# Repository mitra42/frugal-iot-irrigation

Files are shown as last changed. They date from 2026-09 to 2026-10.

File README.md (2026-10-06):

# Frugal-IoT Irrigation

This project is intended to provide solar-powered irrigation for small farms. A set of sectors is watered one at a time, once a day,
each until its soil reaches a target moisture or a time limit runs out, 
with tank-level and battery interlocks that stop the whole run.

It is built on top of Frugal-IoT and both the irrigation and MPPT components draw part of their
inpiration from [OSPIT](https://www.apc.org/en/news/meet-ospit-sustainable-energy-and-irrigation-solution-community-networks)
(Lua on the FF-ESP32-OpenMPPT solar charge controller)
- [OSPIT_COMPARISON.md](OSPIT_COMPARISON.md) describes what is different and why.

This release should work in two hardware environments.

a: The "FF-ESP32-OpenMPPT solar charge controller" in which case it will run MPPT 
This release should work - and do MPPT - on both the "FF-ESP32-OpenMPPT solar charge controller", 
or work without MPPT on  that OSPIT runs on, and 
any similar system of sensors, and pumps. 

[Frugal-IoT](https://github.com/mitra42/frugal-iot) brings: WiFi setup from a phone; MQTT; web and phone dashboards; graphing and over-the-air updates.  

Any of the other features of Frugal-IoT can be easily added to your sketch including, off-internet operation, remote sensors, LoRa, or a wide range of other sensors for example for weather. 

## What it does today

- **Up to N irrigation sectors**, run strictly in order, one valve open at a time.
- **Soil moisture per sector** from RS485/Modbus probes sharing one bus, or from simple analog
  capacitive soil sensors.
- Anomaly handling - for instance, a sector whose probe is **not reporting is skipped**
- **Tank level** from a float sender, with two thresholds: one to begin a run, a lower one to
  abort it. "No tank sensor fitted" is kept distinct from "tank empty".
- **Battery interlock** - irrigation stops below a configurable voltage and resumes above a higher
  one.
- Optional **pump** (driven with the valves) and **load output** (e.g. for a router) (switched by the
  battery interlock) on separate pins.
- Optional **OLED**: Displays battery; sector moistures; tank and communicationss status.
- **Solar charge control** - two-stage MPPT tracking with temperature compensation, a hard
  thermal cut-out, and battery-type profiles.
- **Battery reporting** - state of charge and a health estimate inferred from voltage drop.

## Status

**None of the charge control has run on real hardware yet**, so it ships switched off. 

Run the checks in [TESTING.md](TESTING.md) and then turn on `mppt/automatic`

`HARDWARE-QUESTIONS.md` is a list of things we need someone with the OSPIT hardware to
look at and confirm.

## Hardware

Two boards are supported out of the box. See `platformio.ini` for the full pin list.

| Board | Notes |
|---|---|
| **FF-ESP32-OpenMPPT** | the solar charge controller OSPIT runs on. Pin assignments are OSPIT's own |
| **Lolin S2 Mini** | the same application on a plain dev board, no charging hardware. [docs/hardware/s2_mini](docs/hardware/s2_mini/) is a full reference design - schematic, wiring diagram and BOM |
| other | Setting up support for most other boards is trivial, look in the [Frugal-IoT/examples/all](https://github.com/mitra42/frugal-iot/blob/main/examples/all/platformio.ini) for example configuration for many popular boards or [add a new issue](https://github.com/mitra42/frugal-iot-irrigation/issues/new) in this repo.

You will also need: 12 V valves and a driver for them, one Modbus soil probe per sector, an RS485
transceiver, and optionally a tank float sender and a pump.

For the Lolin S2 Mini there is now a worked hardware design in [docs/hardware/s2_mini](docs/hardware/s2_mini/) at BOM cost about $9/controller + ~$22/sector, detailed explanation of choices in 
[README](docs/hardware/s2_mini/README.md). 

## Building

### PlatformIO (recommended)

```bash
pio run --environment ff_openmppt          # compile
pio run --target upload -e ff_openmppt     # flash
pio run --target uploadfs -e ff_openmppt   # upload data/ (WiFi passwords etc)
```

The Frugal-IoT library is fetched automatically, so a fresh clone needs nothing set up. 
If you are changing the library at the same time, 
see "Building against a local library" in [CLAUDE.md](CLAUDE.md).

### Arduino IDE

1. Install **Frugal-IoT** from Library Manager (or clone it into your `libraries/` folder).
2. Install the ESP32 board support package.
3. Open `frugal-iot-irrigation.ino` - the whole repository folder is the sketch folder.
4. Under **Tools > Board**, pick the board you have. `platform.h` supplies the right pins for it;
   if your board has no section there, compiling stops with a message telling you so.

`platform.h` is generated from `platformio.ini`. If you change pins there, re-run
`scripts/generate_platform_h.bash`, or the two toolchains will disagree.

## First run

1. Flash, then power up. The device makes its own WiFi network - connect a phone to it.
2. A setup page opens (or browse to `192.168.4.1`). Give it your WiFi name and password.
3. **Irrigation starts switched off.** Turn it on in the **Irrigation** section, and set
   the start time while you are there.

`TESTING.md` walks through commissioning a real board step by step, including calibrating the tank
and the battery. `HARDWARE-QUESTIONS.md` is a list of things we need someone with the hardware to
look at.

[docs/bom.md](docs/bom.md) lists the hardware the original OSPIT system is built from - the board,
the sensors, the valves, the pump - with a source for every line.

Because not everyone has sun, a multimeter and a fortnight, `docs/` holds three ready-made plans —
[bench](docs/plan-bench.md), [sunny half-day](docs/plan-sunny-session.md),
[days of running](docs/plan-long-run.md) — each a short ordered list of which Parts of `TESTING.md`
to do. Question 9 of `HARDWARE-QUESTIONS.md` picks one. [docs/sleep-test.md](docs/sleep-test.md) is
the one test that needs its own build, on the `sleep-test` branch.

## Licence

Same as Frugal-IoT. The OSPIT algorithms parts of this are derived from are GPL-2.0-or-later,
Copyright (C) 2026 Corinna 'Elektra' Aichele.

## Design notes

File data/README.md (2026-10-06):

# `data/` - files uploaded to the device's own filesystem

Everything here is copied onto the device with:

    pio run --target uploadfs --environment ff_openmppt

It is **not** part of the firmware, so changing a WiFi password does not mean recompiling.

## The layout: one flat file per setting

Every file sits directly in `data/`, named `<module>.<setting>`, and its contents are the value.
There are no subdirectories - on LittleFS each directory costs a whole 8KB block, which filled the
filesystem on small boards. (A board still holding the old `wifi/`, `frugal_iot/` directories
converts them to this layout by itself, once, at boot.)

Two characters in a name have to be written as codes, because `.` separates the parts:

| In the real name | Write it as |
|---|---|
| `.` | `%2E` |
| `%` | `%25` |

### `wifi.<network name>`

One file per network. The rest of the **file name** is the network name (SSID) and the
**contents** are the password, nothing else - no newline at the end. A device tries every network
it finds a file for, so you can leave several here.

    data/wifi.MyHomeWiFi            <- contains the password
    data/wifi.Cafe 2%2E4G           <- the network called "Cafe 2.4G"

### `frugal_iot.<setting>`

Device settings. The commonest are `project` and `description`, which decide where the device's
readings appear and what it is called on the dashboard.

    data/frugal_iot.project         <- e.g. lotus
    data/frugal_iot.description     <- e.g. Irrigation north field

Any other setting saved from the dashboard is stored the same way - `mppt.automatic`, for example.
You can put one here to have a board start with it.

Every `wifi.*` and `frugal_iot.*` file is in `.gitignore`, because they hold passwords and
site details. This README is not.

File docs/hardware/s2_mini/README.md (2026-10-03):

# Lolin S2 Mini irrigation node — reference hardware

A worked design for the hardware the **`s2_mini`** build needs around it. 

Feel free to modify to your own needs, but check the reasoning below for our design choices so
you can intentionally disagree with them. 

Note - as of September 2026 - none of this has been built on hardware and tested. 

| File | What |
|---|---|
| [`wiring.md`](wiring.md) | **the connection table — the authoritative reference** |
| [`wiring.svg`](wiring.svg) | the same thing as a picture, for assembly |
| [`schematic.pdf`](schematic.pdf) | the circuit, with the values and the reasoning on the sheet |
| [`bom.md`](bom.md) | what to buy, with AliExpress search terms |
| [`bom.csv`](bom.csv) | generated from the schematic |
| [`check_wiring.py`](check_wiring.py) | checks `platformio.ini`, `wiring.md` and the schematic still agree |
| `s2_mini_irrigation.kicad_sch` | the root sheet - a line diagram |
| `driver_valve.kicad_sch` / `driver_switch.kicad_sch` | one output channel, drawn once each |

There is **deliberately no PCB**. This is point-to-point wiring between off-the-shelf modules.

## What the firmware fixes, and what it leaves open

Constraints from code i.e. changing them requires code changes, not just configuration.

- **Outputs are active HIGH.** `Actuator_Digital::act()` is a bare
  `digitalWrite(pin, input->value ? HIGH : LOW)` with no invert flag anywhere in the class. Most
  cheap opto-isolated relay boards are active **LOW**; one of those would open every valve when
  the firmware closed it.
- **The RS485 transceiver must switch direction itself.** `[env:s2_mini]` defines neither
  `SYSTEM_RS485_DE_PIN` nor `SYSTEM_RS485_RE_PIN`, so `System_RS485::txEnable()` short-circuits and
  never drives anything. A plain MAX485 breakout with a DE/RE jumper receives but never transmits.
- **The tank sender divider is 820 Ω to 3V3**, with the sender to ground — `sensor_tank.h` hard-codes
  the raw counts that implies.
- **The battery divider ratio must match `SENSOR_BATTERY_VOLTAGE_DIVIDER`.

## Design decisions

These are our decisions - vary them at will. 

### 12 V in, and nothing about solar

Scope stops at a 12 V input. Charging, panels and MPPT are the FF-ESP32-OpenMPPT board's business
and are not modelled here.

**Reverse polarity: series Schottky, not a P-FET.** A 1N5819 in the positive lead costs ~0.4 V, so
the rail runs at ~11.6 V. A 12 V solenoid operates perfectly well there, which makes the
simplicity worth more than the drop. Use a P-channel MOSFET ideal-diode which would drop ~20 mV instead, if you plan to run this from a nearly-flat battery where every volt counts.

**The 3 A fuse protects the battery, not the board.** Worst case draw is about 0.9 A — one valve
(the sequencer only ever opens one), the S2, and three probes. The fuse is there because a shorted
valve cable across a lead-acid bank is a fire risk and nothing else in the design limits that
current.

### 5 V, and the USB problem

**12 V → 5 V with a buck module, then a series Schottky into VBUS.**

The S2 Mini ties its VBUS pin straight to USB 5 V, so the moment anyone plugs in USB to flash the
board, two supplies meet on one node. The diode plus a deliberate undervolt resolves it: set the
buck to **5.2 V**, and after D2 the rail is ~4.9 V — just *below* USB. When USB is present it wins
and nothing is pushed back into the host port; when USB is absent the buck powers the board. D2
also stops USB back-feeding the buck's output.

**Do not set the buck above ~5.3 V.** Above that, the diode-dropped rail exceeds USB 5 V and the
buck will drive current into the host port through D2 — the exact failure the diode was added to
prevent.

**Why not 12 V → 3.3 V and skip the diode?** Because an LDO cannot do it: at the S2's ~300 mA WiFi
peak, (12 − 3.3) × 0.3 = **2.6 W**, which needs a TO-220 and a heatsink. So 3.3 V would still have
to be a buck, and feeding the 3V3 pin directly then back-drives the module's own regulator and
removes the only thing standing between a drifting trimpot and the ESP32. One 20-cent diode is the
cheaper trade.

### Output drivers: discrete MOSFETs, no relays

Five identical low-side channels: 100 Ω gate series resistor, 100 k gate pull-down, IRLZ44N,
1N5819 flyback across the load.

**Why not relay modules?** They are easy to buy, but they are usually active LOW (see above), they
draw coil current continuously while a valve is open, and they wear out. A logic-level MOSFET is
cheaper, silent, and its natural polarity is the one the firmware already uses.

**Why IRLZ44N?** Availability, not merit. It is logic-level (V<sub>GS(th)</sub> 1.0–2.0 V), it is
comfortably in saturation at a 3.3 V gate for a 0.5 A solenoid, and being rated 55 V / 47 A — wildly
more than needed — is exactly why it is cheap and stocked everywhere. An AO3400 is the SMD
equivalent; an IRLB8721 is slightly better and slightly harder to find.

**Pump and load are 12 V DC, and mains is out of scope.** If the pump or the router is
mains-powered, drive an external Sonoff from the frugal-iot server rather than putting mains on
this board. Nothing here is rated for it, and mixing mains with low voltage raises the safety bar a
long way past what a drawing like this can carry responsibly. That decision is also what removed
two relays, two coil currents and a pile of clearance requirements from the design.

### Failure modes — a dead controller must not leave water running

Three independent layers, two of which constrain purchase decisions.

1. **Normally-closed solenoids only.** If 12 V disappears, an NC valve shuts mechanically, with no
   circuit involved. This is the layer that actually satisfies the requirement.
   **Latching valves must not be used** — they hold their last state, and the firmware could not
   drive one anyway: it holds a level for a duration, where a latching valve needs an H-bridge and
   two pins per valve.
2. **The 100 k gate pull-downs.** Covers the case of 12 V present, controller dead, resetting, or still booting.
   The pull-down holds the gate due while the ESP32 GPIOs are floating before `setup()` runs and during a brownout,
3. **The battery interlock**, at 12.6 V ± 0.2 (`IRRIGATION_LVD_IRRIGATION_MV`). This covers the slow
   case — a sagging battery that can still hold a solenoid open but can no longer run the system.

None of the five outputs is a strapping pin (those are GPIO0, GPIO45 and GPIO46 on the S2), so
nothing here affects boot mode.

### Battery sense

**220 k / 39 k, ratio 6.641, with 100 nF at the pin.** 15 V puts 2.26 V on the pin, inside the S2
ADC's 0–2500 mV linear range at the default attenuation; 12.6 V puts 1.90 V. The values are high
because a 12 V bank moves slowly, so 49 µA of standing drain is worth more than the extra
resolution.

**The capacitor is required, not optional.** Source impedance is 220k∥39k = 33 kΩ, well above the
ADC's ~10 kΩ preference. 100 nF gives τ = 3.3 ms against a 10 s sample interval, so the reading is
fully settled.

If, for software testing, you fit no divider and run on USB, comment `SENSOR_BATTERY_PIN` back out as 
a floating pin looks similar to brownout causing a hard shutdown.

### RS485 and the probes

**One 120 Ω termination, at the far end of the bus.** Not on this board — at the last probe.

**Bias resistors are drawn but marked DNP**, because most auto-direction modules already fit bias
and termination and a second set makes things worse. If yours does not, the arithmetic matters:
fail-safe bias has to hold the idle bus above 200 mV differential, and with 120 Ω at *both* ends
(60 Ω effective) a 680 Ω pair gives only 3.3 × 60/1420 = **139 mV**, which is not enough. With one
termination, 680 Ω gives 268 mV and is right. Terminate both ends and you need 470 Ω.

**Probes run from the 12 V rail**, since SEN0600-class probes accept 5–30 V. No separate supply.

**Connect them one at a time, in sector order.** `SENSOR_SOILMODBUS_AUTOPROVISION` writes an
address to whichever probe answers the factory address, and every probe ships as address 1 — so two
unprovisioned probes on the bus at once cannot be told apart.

### Grounding

Star point at the 12 V input negative terminal. Solenoid return currents must not share a conductor
with the ground path back to the S2: a 0.5 A pulse down a shared return puts tens of millivolts
under the battery and tank readings. Run a separate wire from each driver's source to the star
point rather than daisy-chaining them.

## Deep sleep concerns

**This board does not sleep, and should not.** `frugal_iot.configure_power(Power_Loop, 10000, 10000)`
keeps it awake on a 10-second cycle. That is the right call here: the ESP32 draws well under a watt
against valves and pumps that draw orders of magnitude more, so sleeping saves nothing that
matters, and a deep sleep mid-run would abandon the run — `Control_Irrigation` returns to idle in
`setup()`.

Recorded here because the findings would otherwise be scattered, and because anyone who tries to
add sleep later will hit all of them:

- **GPIO38 and GPIO40 are not RTC pads on the S2.** They float on wake, and
  `Actuator_Digital::setup()` prints a warning saying so. On this board that means the pump and
  load outputs, and the gate pull-downs are what make it safe.
- **`Actuator::preserveDuringSleep` exists to hold pins through a sleep, and the low-voltage path
  deliberately does not use it.** `System_Power::checkLevel()` goes to deep sleep as fast as it
  can, without `prepare()`, because the point is to get there before the rail collapses. The cost
  is that pins are released — and that is the *correct* trade here, because holding them would hold
  a valve **open** on a flat battery.
- **`System_Modbus` loses its `connected` flag**, so the first read after each wake costs a 2 s
  ModbusMaster timeout per absent probe.
- **The tank and battery readings are taken fresh on each wake** and need no state, so those are
  the parts that would survive sleep unchanged.

## Known-unmeasured

- Nothing in this design has been built. The values are arithmetic and datasheet figures.
- The tank sender's 0 Ω / 170 Ω / 820 Ω figures come from a comment in OSPIT's `irrigation.lua` and
  were never measured. Calibrate rather than trusting them.
- Solenoid current is assumed ~0.5 A. Check yours before trusting the 3 A fuse.

## Regenerating

The schematic and the wiring diagram are generated, not hand-drawn, so that the pin assignments
cannot drift from `platformio.ini`. The generator scripts live outside the repo; the
committed artefacts are the schematic, the exports and `wiring.md`. To verify they still agree:

```bash
python3 docs/hardware/s2_mini/check_wiring.py
```

It compares `platformio.ini`, the table in `wiring.md` and the schematic's own netlist, and exits
non-zero if any of the three disagree.

ERC is clean, and the netlist was diffed pin-by-pin against the intended connection list.

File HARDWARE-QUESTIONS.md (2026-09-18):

# Questions for whoever has the FF-ESP32-OpenMPPT board

We have added support for a board we do not have. Everything below is something you can see or
measure - none of it needs any knowledge of the software.

**Photographs are very welcome.** A clear photograph of the whole board, plus close-ups of
anything a question mentions, often answers several questions at once.

Please number your answers to match. 

Posting to a new issue on the repo is probably the best way, though email to support@naturalinnovation.org 

---

## 1. Which board is it?

Look on the board for a printed version number. It is usually near an edge, or near the name of
the board, and looks like `v1.0`, `v1.1` or `v1.2`.

- What does it say?
- If there is no version number, please photograph both sides of the board.

**Why we ask:** three versions of this board exist and they behave differently. We currently
assume the newest.

---

## 2. The part marked D6

Find the printed label **D6** on the board. It is near where the solar panel wires connect.

Which of these do you see? Please also photograph it closely.

- **(a)** A small black or grey component with a stripe or line printed at one end. That is a
  diode.
- **(b)** No component — instead, a short piece of wire, or a blob of solder, joining the two
  metal pads to each other.
- **(c)** Two bare metal pads with nothing between them and nothing joining them.

**Why we ask:** if the diode is there, the board loses about 0.3 V of the panel's voltage, and our
software must add that back. If it has been replaced by a wire, it must not.

---

## 3. The temperature sensors

This board can have up to three temperature sensors. They are small components, often in a metal
tube on the end of a cable, or a small black rectangle soldered flat to the board.

- How many can you find?
- For each one: where is it? On the board itself, attached to the metal heatsink, clipped to the
  battery, or hanging free in the air?
- Please photograph each one and where it is attached.

**Why we ask:** the software needs to know which reading is the battery and which is the board, and
they look identical electrically. Physical position is the only way to tell.

---

## 4. Is there a temperature sensor built into the board itself?

Separate from question 3. Look for two very small components side by side, close to the large metal
heatsink, labelled something like **D1 D2** or **T1**, with a resistor beside them.

- Is there anything like that? Photograph it.

**Why we ask:** there are two possible ways this board measures its own heat, and we do not know
which one your board uses. We only want to include the right one.

---

## 5. What is connected to the load output?

There is one output meant for a permanent load, separate from the valves.

- Is anything connected to it? What?
- We have been told it is often a WiFi router. Is that the case here?

**Why we ask:** the software can switch this output off when the battery is low, and can restart
it if the internet stops working. Both are only sensible if we know what is plugged in.

---

## 6. Is there a USB socket on the board?

- Is there a USB socket meant for **supplying power to something else** (as opposed to the one you
  plug into a computer)?
- If yes, is anything plugged into it?

**Why we ask:** on the original design this socket shares a connection with one of the irrigation
valves — you can have the third valve, or the USB socket, but not both. We need to know which one
you need.

---

## 7. The tank sensor connection

- Is a water tank sensor connected? What kind — a float on an arm, a float on a rod, something
  else?
- Which terminal on the board is it connected to? Please photograph it, including any printed
  label beside that terminal.

**Why we ask:** the original documentation is contradictory about which connection the tank sensor
uses. One note says it is a temperature input. We would rather know than guess.

---

## 8. The battery and the solar panel

From the labels on them:

- **Battery:** what type? The label may say AGM, GEL, Flooded (sometimes "wet"), or LiFePO4 /
  Lithium. What capacity, in Ah?
- **Solar panel:** the label on the back usually lists several numbers. We need **Voc** (or "open
  circuit voltage"), **Vmp** or **Vmpp** (or "voltage at maximum power"), and the **watts**.
- Please photograph both labels.

**Why we ask:** different battery types must be charged to different voltages. Charging one type to
another type's voltage will damage it, sometimes quickly.

---

## 9. What can you measure, and for how long?

- Do you have a multimeter? (We assume yes.)
- Can you leave the system running for several days and come back to it, or do you only have it for
  a short time?
- Is there a sunny place to test, and roughly what hours does the sun reach the panel?

**Why we ask:** some of the checks need readings taken at different times of day, and some need
none of that. Please still tell us your answers — but **do not wait for us before starting.** Find
your situation in this table and go straight to that plan.

| Your situation | Your plan |
|---|---|
| An afternoon with the board, sun or no sun | [docs/plan-bench.md](docs/plan-bench.md) |
| Sun on the panel, a multimeter, an hour and a half | [docs/plan-sunny-session.md](docs/plan-sunny-session.md) — do the bench plan first if you can |
| The board can stay somewhere sunny for three days or more | [docs/plan-long-run.md](docs/plan-long-run.md) — after both of the above |
| No multimeter | [docs/plan-bench.md](docs/plan-bench.md), skipping Part E. The two tests that need a meter are the ones we most need — there is a note at the end of that plan about what it costs us |

Each plan is a short list pointing into [TESTING.md](TESTING.md), which has the actual steps. If
none of the four describes your situation, tell us what you have got and we will write one that
does.

---

## 10. What happens to the outputs when the board is asleep?

This one needs a measurement rather than a look, a multimeter, and a **different build of the
software**. **It can wait until you have done the rest** — and you do not need anything from us to
start it: the software is on a branch called `sleep-test`, and
[docs/sleep-test.md](docs/sleep-test.md) says how to build it, how to tell when the board is
asleep, and exactly what to measure.

The board can be told to sleep when the battery is low, so that the solar panel gets a chance to
recharge it. But while an ESP32 sleeps, its output pins are normally *released* — they stop being
driven — and we do not know what this board does then. The original software sets pin 14 with a
"pull-up", which if it still applies while asleep would switch the load **on** at exactly the
moment we were trying to save power.

That build sleeps on a repeating cycle — five minutes awake, two minutes asleep — so nothing has to
be triggered or timed. It asks for six readings: the pin 14 output terminal — the page calls it
**Pump**, the original software uses it as the load switch — switched on and then switched off,
each measured while awake and then again while asleep, and the solar panel voltage the same way.

**Why we ask:** if sleeping turns the load back on, or stops the battery charging, then sleeping
to save power makes things worse rather than better, and we will leave the feature switched off.

---

## 11. Anything that surprises you

If anything on the board looks damaged, modified, hand-soldered, or simply different from what
these questions describe, please tell us and photograph it. A board that has been repaired or
changed is very common and completely fine — but only if we know.

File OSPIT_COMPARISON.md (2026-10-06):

# How this differs from OSPIT

This application started as a port of
[OSPIT](https://www.apc.org/en/news/meet-ospit-sustainable-energy-and-irrigation-solution-community-networks),
the NodeMCU-Lua firmware for the FF-ESP32-OpenMPPT board, and parts of it are still close ports.
This file collects what changed and why, and what looks wrong in OSPIT, so that the comments in
the code can stay short. The code says *what* it does; this says how it differs from what OSPIT
did.

OSPIT sources referred to below are from a translated repo that may be out of date. This file only covers what affects this application.

OSPIT's main files, for reference:

| OSPIT file | What it does | Here |
|---|---|---|
| `irrigation.lua` | the sequencer and the tank gauge | `control_irrigation.*`, `sensor_tank.*` |
| `mp2.lua` | MPPT, charge limit, state of charge, battery health, low-voltage disconnect, USB disconnect | `control_mppt.*`, `control_soc.*`, `control_health.*`, the `Control_Hysteresis` interlocks in the `.ino` |
| `display.lua` | three status pages | `control_oled_irrigation.*` |
| `is.lua` | timers, GPIO setup | the library's `System_Power` and `Actuator_Digital` |
| `owids.lua` / `owread.lua` | DS18B20 probes | the library's `Sensor_DS18B20` |
| `config_default.lua` | defaults | `platformio.ini` and the schema defaults |

---

## 1. Hardware and pins

The `ff_openmppt` pin assignments in `platformio.ini` are OSPIT's own, read out of its Lua:

| Pin | Use | Where OSPIT says so |
|---|---|---|
| 26, 27, 12 | valves 1-3 | `irrigation.lua`: `local valves = {26, 27, 12, 14}` |
| 14 | pump or load | `irrigation.lua` drives it with the valve when `pump_is_load` is false; `mp2.lua` also uses it as the low-voltage load disconnect, and `control.lua` exposes it as "Load power output". Three jobs, one pin. |
| 16 / 17 | RS485 rx / tx | `modbr.lua`: `uart.setup(2, ..., {tx = 17, rx = 16})` |
| 32 | tank gauge | `irrigation.lua`: `ADCmeasure(4, 2)`, i.e. ADC1 channel 4 |
| 33 | battery | `mp2.lua` `Voutmeasure()`: ADC1 channel 5, 1k/15k divider, ratio 0.0625, so a factor of 16 |
| 34 | panel | `mp2.lua` `Vinmeasure()`: 1k/27k divider, ratio 0.035714, so a factor of 28 |
| 21 / 22 | OLED I2C | `init.lua` loads `SSD1306.lua` |

What changed:

- **Three valves, not four.** OSPIT's list has a fourth valve on pin 14, the same pin as the
  pump/load. Here pin 14 is a pump or a load and never a valve.
- **Pin 14: pump or load, chosen at build time.** OSPIT has one output with a runtime flag,
  `pump_is_load`. Here there are two independent optional pins, `IRRIGATION_PUMP_PIN` and
  `IRRIGATION_LOAD_PIN`. `IRRIGATION_PUMP_PIN` is the same as `pump_is_load = false`, and
  `IRRIGATION_LOAD_PIN` is the same as `pump_is_load = true`. On the FF board they cannot both be
  pin 14, so `platformio.ini` sets one and comments out the other. OSPIT's default is the load
  role. The pump role is used here because it exercises the irrigation path.
- **Pin 12: valve 3 or USB supply, chosen at build time.** OSPIT decides at runtime: if probe 3
  does not answer (`shumidity3 == -127`), `irrigation.lua` skips sector 3 and `mp2.lua` uses the
  pin for USB load control. Here you define either `IRRIGATION_VALVE3_PIN` or
  `IRRIGATION_USB_PIN`. The skip itself is kept for another reason, see
  [Skipping a sector](#skipping-a-sector).
- **The display is the I2C SSD1306, not the SSD1327 SPI panel.** The SSD1327 needs pins 16 and 17
  for dc and rst, and the RS485 probes use those pins. OSPIT makes the same choice: `init.lua`
  loads `SSD1306.lua` and leaves the SSD1327 line commented out.
- **GPIO32 may not be the tank.** `mp2.lua`'s header comment calls GPIO32 a temperature sense
  input, but `irrigation.lua` reads it as the tank. Question 7 in `HARDWARE-QUESTIONS.md` asks
  someone with the board to check.
- **The battery divider.** At 12.6 V, OSPIT's 1k/15k divider puts only 0.79 V on the pin, about a
  quarter of the ADC's range. If you are building new hardware, 3k3/15k (a factor of 5.546) gives
  noticeably better resolution.

---

## 2. Irrigation sequencer (`irrigation.lua` → `Control_Irrigation`)

What is the same: once a day, take each sector in turn, open its valve until the soil reaches its
target or a maximum time runs out, then move on. Stop if the tank runs dry or the battery
interlock opens.

Future versions will add functionality here, for example so that a sector might run twice a day or be temperature dependent. 

| OSPIT | Here | Notes |
|---|---|---|
| `i_hr` | `irrigation/hour` | default 3 in both |
| — | `irrigation/minute` | OSPIT starts on the hour |
| `i_vlv_opn` | `irrigation/maxminutes` | |
| `i_nbld` | `irrigation/enabled` | off by default in both |
| `i_lvl1..4` | `sectorN/target` | |
| `low_voltage_disconnect_state` | `irrigation/power` | see [Battery interlocks](#battery-interlocks) |
| `i_tanksens` | — | here, a missing tank sensor is detected rather than configured |
| — | `irrigation/active` | which sector is running; OSPIT has no equivalent |

### Skipping a sector

OSPIT skips a sector whose probe reads `-127` without touching its valve. In OSPIT this is how the
board is configured (see pin 12 above). Here a sector exists because you constructed one, so that
reason is gone. The skip stays because driving a valve with no feedback is worse than not
watering.

The same rule applies when closing. OSPIT's reset branch closes only valves whose probe is not
`-127`, so that it does not switch off the USB charger on pin 12. `closeAll()` does the same, so
a sector with no reading is never driven either way.

### Closing everything at the end of a run

OSPIT's reset branch writes 0 to every valve at the end of a sequence, whoever opened it.
`closeAll()` does the same. Without it, a valve opened by hand from the portal would never close,
because `OUTbool::set()` only sends on a change.

### Interlocks abort the whole sequence

This matches OSPIT's "Irrigation Emergency Stop": an interlock that opens part way through
abandons the cycle, not just the current sector.

**One difference:** OSPIT's emergency stop clears the active valve but leaves `irrigation_done`
false, so its 6-second loop starts again for the rest of the scheduled hour. Here, a cycle that is
blocked at the scheduled moment (a tank still refilling at 03:00, a momentary battery dip) is
written off until the next day. There is a TODO in `Control_Irrigation::periodically()` to add a
retry window if that matters in practice.

### Battery interlocks

OSPIT gates irrigation on `low_voltage_disconnect_state`, the same flag that disconnects the load,
so both switch at 11.9/12.3 V. Here every consumer has its own `Control_Hysteresis`, and the
thresholds set the order things are shed as the battery falls:

| Consumer | Off / on | Why this order |
|---|---|---|
| USB supply | 12.8 / 13.4 V | least important |
| Irrigation | 12.4 / 12.8 V | a pump is the heaviest intermittent load, and watering can wait a day |
| Load (router) | 11.9 / 12.3 V | last, because losing communications means losing the ability to find out what went wrong |

Setting `IRRIGATION_LVD_IRRIGATION_MV=12100` in `platformio.ini` goes back to OSPIT's behaviour.

### Low-voltage deep sleep

OSPIT's `low_voltage_sleep_enabled` defaults to true: below 11.9 V the node deep sleeps for five
minutes at a time. The library supports this (`SYSTEM_POWER_LOW_MV` / `SYSTEM_POWER_LOW_MS`), but
it is **not enabled here yet**. We do not know what the board's outputs do while the ESP32 is
asleep:

- A GPIO is released in deep sleep unless it is explicitly held, and `is.lua` configures pin 14
  (the load switch) with `PULL_UP`. If that pull-up turns the router back on during a sleep meant
  to save power, sleeping makes things worse.
- If the DAC on pin 25 stops charging during sleep, the battery cannot recover during the very
  sleep meant to let it.

For scale: the ESP32 draws well under a watt, so it is not what flattens an 18 Ah battery. The
load is, and the load interlock already sheds that at 11.9 V. `docs/sleep-test.md` describes the
measurement that would settle it.

---

## 3. Tank gauge (`irrigation.lua` → `Sensor_Tank`)

**OSPIT's tank gauge does not measure a level. It only reports whether the sender is connected.**

The hardware, from the comment in `irrigation.lua`: a float sender that reads 170 Ω full and 0 Ω
empty, with an 820 Ω series resistor to 3v3. So:

| State | Pin voltage | 12-bit counts at 11 dB |
|---|---|---|
| full, 170 Ω | 0.567 V | about 703 |
| empty, 0 Ω | 0 V | 0 |
| sender disconnected | pulled to 3v3 | about 4095 |

OSPIT's live code is:

```lua
local tankgaugeadc = ADCmeasure(4, 2)
if tankgaugeadc > 4000 then tankgauge = 0 end
if tankgaugeadc < 3000 then tankgauge = 1 end
```

This cannot tell a full tank from an empty one, because every connected reading is below 3000. It
reports an open circuit as 0, i.e. as an empty tank. Because the sequencer then tests
`tankgauge <= 0 and i_tanksens == true`, a node with `i_tanksens` on and its sender unplugged
refuses to irrigate, and looks exactly like a node whose tank is dry. A genuinely empty tank does
not stop irrigation at all. Between 3000 and 4000, `tankgauge` keeps its previous value.

An earlier version that computed a percentage is still in the file, commented out. It never ran,
and it read a different ADC channel (`ADCmeasure(0, 40)`) from the one it configured.

Here the two states are kept apart:

- no sender fitted, or a broken cable → `validate()` fails → `nan` → the tank does not block
  irrigation
- a real level → 0-100 %, and a genuine low level does stop irrigation

The default calibration (0 and 703 counts) is calculated from the resistances in OSPIT's comment
and has never been measured. Use the portal's Tare and Calibrate. The disconnect threshold of 3000
is the bottom of OSPIT's 3000-4000 dead band.

---

## 4. Display (`display.lua` → `control_oled_irrigation`)

OSPIT shows three pages and moves to the next one each time the display timer fires. Here the
three pages are `Control_Oled` subclasses in a `Control_Carousel`, so they can also be selected by
hand.

- **Page 1 (power):** OSPIT's page is mostly MPPT: open-circuit voltage, tracking voltage, charge
  state and battery temperature. Ours shows battery volts, state of charge, panel volts and the
  charger's state word.
- **Page 2 (soil):** a sector with no reading prints `--` where OSPIT prints `-127`. The tank
  prints `--` when no sender is fitted, which OSPIT cannot distinguish from empty. A `*` marks the
  sector that is watering; OSPIT has no equivalent.
- **Page 3 (network):** follows `display.lua`.

---

## 5. Solar charge control (`mp2.lua` → `Control_MPPT`)

The method is OSPIT's: **fractional Voc**. Unload the panel, measure the open-circuit voltage, and
ask for `Voc / 1.24` (about 0.8 × Voc). The DAC is an inverse throttle in both: a higher step
means less current.

### How often it sweeps

OSPIT re-runs `mp2.lua` every 15 s (`is.lua`), and its sweep takes about a second. Ours cannot: the
panel voltage only arrives through the sensor path, once per wake cycle, so a sweep costs a whole
cycle of not charging. Sweeping every cycle would halve the harvest. `CONTROL_MPPT_SWEEP_S`
defaults to 300 s instead. Voc moves with panel temperature over tens of minutes, so this costs
very little tracking accuracy.

### Regulation near full charge

OSPIT's `Voutctrl()` runs every 600 ms against a reading it takes itself, and moves the DAC by one
step outside a ±30 mV band. Ours runs once per wake cycle (about 10 s) against the battery
sensor's reading. At one step per cycle it would take most of an hour to cross the range, so it is
proportional and slew-limited: `error / CONTROL_MPPT_REGULATE_MV_PER_STEP`, clamped to
`CONTROL_MPPT_MAX_SLEW`. `CONTROL_MPPT_OVERSHOOT_MV` is the backstop that makes the slow loop safe.

### The DAC mapping: 285, not 255

OSPIT maps panel voltage onto the DAC as

```lua
dac1value = (v_mpp_estimate - Vmpp_min) / ((Vmpp_max - Vmpp_min) / 285)
```

The DAC is 8-bit, so dividing by 285 means the top tenth of the range is unreachable. This may be
a deliberate correction for a transfer function that is not quite linear, or it may be a mistake;
the code does not say. It is `CONTROL_MPPT_DAC_SPAN` here, and Part H of `TESTING.md` is the
measurement that would settle it. The per-revision Vmpp ranges (FF v1.0, v1.1, v1.2) are also
OSPIT's.

### When the panel is dark

OSPIT writes step 29 when the panel is dark, and we do not know why. It is a low step, so it asks
for maximum current. That is harmless in the dark, and it means charging starts as soon as the sun
returns rather than at the next sweep. That is the only explanation we can see.
`CONTROL_MPPT_IDLE_STEP` keeps the value.

OSPIT zeroes its panel readings when `V_oc < V_out + 0.2`. Here the same test uses
`CONTROL_MPPT_VOC_MARGIN_MV`, 500 mV by default.

### Heatsink protection

OSPIT has one mechanism: above `heatsink_derate_start_c` (60 °C), it lowers the charge target by
100 mV on each run, and it restores the target below 58 °C.

Here 60 °C is a **hard cut**: charging stops on that cycle and stays stopped until the board has
cooled to 53 °C. OSPIT's progressive back-off is kept but starts lower, at 55 °C.

The progressive back-off cannot be the only mechanism. Lowering the target does nothing while the
battery is below it, because in bulk the target only decides when to start regulating. So the
back-off only takes effect once the target has been walked down below the battery's actual
voltage, and every step above that is dead travel. Measured, at a 10 s cycle and 100 mV per step:
with the battery near full it cuts in after about 30 s, but with a discharged battery at 12.4 V it
takes about 180 s. The discharged battery draws the most current and makes the most heat, so the
response was slowest exactly when it was needed most.

(An earlier version of our port also capped the total back-off. The cap stopped the target above a
discharged battery's voltage, so the protection never took effect at all.)

The restore point is 53 °C rather than 58 °C so that, after a hard cut, charging does not cycle on
and off around the limit.

### Battery profiles

The charge-end voltages, temperature coefficients and hot-battery voltages per chemistry are
OSPIT's `battery_profile_defaults()`. So is the 42 °C hot-battery limit (`batt_charge_limit_temp_c`).

OSPIT has an `is_custom_profile` flag and a parallel set of `batt_*` variables for a custom
profile. Here, selecting a profile *writes* `chargeend`, `tempcoeff` and `hotcharge`, and editing
one of them afterwards keeps the edit. That is all "Custom" means here, so it needs no flag.

---

## 6. Heatsink temperature from diodes (`Sensor_Heatsink`)

OSPIT computes the temperature from raw ADC counts, a hand-calibrated reference voltage and the
6 dB attenuator setting:

```
V = ((raw / 4095) * (Vref * 0.002)) / 1.06
T = -50 + ((1.273 - V) / 0.0048)
```

This works out as `T = 215.2 - 0.2083 × mV`, i.e. 913 mV at 25 °C and 4.8 mV per degree. Those
are the defaults here. We do not copy the arithmetic because we read
`analogReadMilliVolts()`, which applies the chip's factory calibration and already allows for the
attenuator, so `Vref`, the 0.002 and the 1.06 have no equivalent.

OSPIT treats a reading near the supply rail as "sensor missing, or connected the wrong way round".
`SENSOR_HEATSINK_MV_DISCONNECTED` (2500 mV) is the same test.

---

## 7. State of charge (`mp2.lua` → `Control_SoC`)

`mp2.lua` has eight overlapping heuristics with hand-tuned constants. Most of them try to estimate
the state of charge **while charging**, without a current sensor, by reasoning about the ratio of
open-circuit to tracking voltage, whether the voltage is still rising, and so on. That cannot
really be done: without the current, the charging voltage describes the charger, not the battery.

They are deliberately not ported. What is ported is the part that works:

- a standard resting-voltage table per chemistry, interpolated
- the estimate is **frozen** while the panel is above the battery, rather than following the
  charger up
- slew-limited, so a pump starting does not move it

Here it is **reporting only**, published read-only. In OSPIT `charge_state` also feeds the system
status. `Control_MPPT` measures its own thresholds and never reads it.

---

## 8. Battery health (`mp2.lua` → `Control_Health`)

The method is OSPIT's, and it is a reasonable one for a system with no current sensor. Over a
six-hour window at night:

```
health % = (6 h × av_pwr) / ((SoC at 22:00 - SoC at 04:00) / 100 × ah_batt) × 100
```

| OSPIT | Here |
|---|---|
| `ah_batt` | `batteryhealth/capacity` |
| `av_pwr` | `batteryhealth/load` |
| `pv_watt` | `batteryhealth/panelwatts` |
| `critical_storage_charge_ratio` (5.0) | `CONTROL_HEALTH_MIN_RATIO` |
| the "Healthy" / "Battery level low" / "Energy storage capacity too small" status | `batteryhealth/advice` |

### A flaw in OSPIT's version, fixed here

OSPIT measures from 22:00 to 04:00 and irrigates at 03:00 (`i_hr = 3`). On any night the
irrigation runs, the pump's draw falls inside the measurement window but is not included in
`av_pwr`. The battery then looks much more worn than it is, and only on nights it waters, so the
figure jumps around for no visible reason.

Here the window is discarded if `irrigation/active` is non-zero at any point during it.

### Other differences

- Nothing is reported until a complete, uninterrupted window has passed. OSPIT starts from a
  default of 100.
- A window in which the estimate did not fall is reported as "voided", not as 100 %.
- Here, the storage-ratio advice uses the rated capacity until there is a measured health figure,
  so it is available from the first day.

---

## 9. Not ported

These were left out on purpose, not overlooked:

- The eight state-of-charge heuristics (see [§7](#7-state-of-charge-mp2lua--control_soc)).
- Low-voltage deep sleep is available but not enabled (see
  [§2](#low-voltage-deep-sleep)).
- The runtime overloading of pins 12 and 14 (see [§1](#1-hardware-and-pins)).
- Everything in OSPIT that the library already does a different way: the web server, FTP, telnet,
  the Lua shell, OTA, MQTT, configuration storage and the router scripts.

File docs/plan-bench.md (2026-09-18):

# Plan 1 — everything that does not need the sun

**This is the plan to start with**, whoever you are and whatever else you can do later. Nothing in
it depends on the weather, and none of it can harm the battery or the board.

## Is this the right plan for you?

Yes, if you have the board for **an afternoon or more**. It does not matter whether the sun is out,
and it does not matter whether the board is in its final position — a table indoors is fine.

If you also have sun and a multimeter, do [Plan 2](plan-sunny-session.md) afterwards. If you can
leave the board running for days, do [Plan 3](plan-long-run.md) after that.

## What you need

- The board, a USB data cable, a computer, and a phone or laptop with WiFi.
- A 12 V battery. **No solar panel needed** — if one is connected, disconnect it while you work.
- A multimeter, for one step only (see below if you have not got one).
- Whatever you have of: the soil probes, the valves, a tank float sensor, a bucket of water.

**Roughly 3 hours**, of which about half is waiting for things.

## The order

Work through [TESTING.md](../TESTING.md), in this order, skipping nothing in between:

| | Section | About | Needs |
|---|---|---|---|
| 1 | [Part A](../TESTING.md#part-a--getting-it-running) | getting the software on and talking to it | 30 min |
| 2 | [Part B](../TESTING.md#part-b--the-outputs-valves-pump-load) | the valve, pump and load outputs | 20 min, meter or one valve |
| 3 | [Part C](../TESTING.md#part-c--the-soil-probes) | the soil probes, added one at a time | 30 min, the probes |
| 4 | [Part D](../TESTING.md#part-d--the-water-tank-sensor) | the tank sensor | 30 min, the float sensor |
| 5 | [Part E](../TESTING.md#part-e--the-battery-reading) | is the battery voltage it reports correct | 10 min, **meter** |
| 6 | [Part F](../TESTING.md#part-f--a-complete-irrigation-run) | one whole watering run, start to finish | 30 min, water |
| 7 | [Part G](../TESTING.md#part-g--the-charge-controllers-own-measurements), steps **G2, G3 and G4 only** | which temperature sensor is which | 30 min |

**Skip step G1** — it needs the sun on the panel, and it belongs to [Plan 2](plan-sunny-session.md).

**Do not go on to Part H or Part I.** Both need sun, and Part I should not be switched on until
Part H's numbers have been looked at.

If you have not got some of the hardware — no probes, no tank sensor, no valves — skip that Part
and say so. The Parts do not depend on each other's equipment.

## If you have not got a multimeter

Do everything above except **Part E**, and tell us so.

It is worth knowing what this costs. Part E is what tells us whether the battery voltage the board
reports is the real one, and every protection in the software — when it stops watering, when it
sheds the load, when it decides the battery is full — is a decision made on that number. Without
Part E we cannot tell a correct reading from one that is out by a volt.

Parts G1 and H, in [Plan 2](plan-sunny-session.md), cannot be done at all without a meter, and
Part H is the single most useful measurement in the whole document.

Borrowing a meter for one afternoon is worth more to us than everything else on this list put
together. Almost any meter will do; it only has to read DC volts up to about 30 V.

## When you have finished

Send back what [How to report what you find](../TESTING.md#how-to-report-what-you-find) asks for —
step numbers, the actual numbers you measured, and photographs of anything that did not look like
the description.

Also send your answers to [HARDWARE-QUESTIONS.md](../HARDWARE-QUESTIONS.md) if you have not already.
Several of them are questions the steps above will have put in front of you anyway.

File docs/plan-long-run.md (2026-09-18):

# Plan 3 — leaving it running for days

This is the plan for someone who can put the board somewhere sunny, **switch charging on, and come
back to it over several days**. It is the only plan that tells us whether the thing works as a
solar charge controller rather than as a set of measurements.

## Is this the right plan for you?

Only if all of these are true:

- [Plan 1](plan-bench.md) is done.
- [Plan 2](plan-sunny-session.md) is done, **and someone has looked at your Part H numbers**. This
  matters: Part I lets the board decide its own charging, unattended, and if Part H showed our idea
  of the hardware is wrong then that is not something to leave running.
- The board can stay where it is, with sun on the panel, for **three days or more**, and you can
  look at it once or twice a day.
- The battery it is charging is one you know the type of — AGM, GEL, flooded, or LiFePO4.

If you are not sure what battery you have, **stop and ask**. Charging a battery to the wrong
voltage shortens its life, and in the worst case can make a sealed battery vent gas. This is the
one thing on any of these plans that can damage something.

## The order

| | Section | About | When |
|---|---|---|---|
| 1 | [Steps I1 and I1b](../TESTING.md#step-i1--set-the-battery-type) | tell it what battery, check the battery temperature sensor | 15 min |
| 2 | [Step I2](../TESTING.md#step-i2--switch-it-on) | set **Automatic** on | 1 min |
| 3 | [Step I3](../TESTING.md#step-i3--watch-what-it-says-it-is-doing) | watch what it says it is doing | first hour, then daily |
| 4 | [Step I4](../TESTING.md#step-i4--check-it-stops) | check it stops when the battery is full | day 1 or 2, afternoon |
| 5 | [Step I5](../TESTING.md#step-i5--the-usb-supply-if-your-board-has-one) | the USB supply, if your board has one | any time |
| 6 | [Step I7](../TESTING.md#step-i7--battery-charge-and-health-they-look-after-themselves) | charge and health readings | day 3 |
| 7 | [the sleep test](sleep-test.md) | what the outputs do while the board sleeps | last, needs a different build |

**Leave the sleep test until the end.** It needs software from a different branch, so you have to
flash the board again, and doing it earlier would interrupt the days of charging that are the
point of this plan.

## What to write down, and when

Once a day is enough, but please do it on paper or in a message at the time rather than from
memory afterwards:

- the time of day, and roughly what the weather was doing
- the **battery voltage** and the **Target** voltage the page shows
- which **stage** it says it is in
- the **panel voltage** and the **DAC step** number
- any temperature it shows

A week of once-a-day readings tells us more than an hour of watching it closely, because the
things that go wrong with a charge controller mostly go wrong overnight, or on the third cloudy day,
or when the battery reaches full for the first time.

## What we are watching for

- Does it ever ask for **more** charging than the panel can give, and sit there stuck?
- When the battery reaches full, does it **stop**, or does it keep pushing?
- Does the **Target** voltage move with temperature, as
  [Part I](../TESTING.md#part-i--letting-it-charge-by-itself) describes?
- Does it recover sensibly after a cloudy spell or overnight?
- Does the state-of-charge figure look anything like the truth?

## If something looks wrong

Set **Automatic** back to off. That stops the board charging on its own and puts it back where
[Plan 2](plan-sunny-session.md) left it — nothing is lost, and you can leave it there safely until
we have talked.

Tell us what it said at the time. The numbers on the page at the moment it looked wrong are worth
far more than a description afterwards.

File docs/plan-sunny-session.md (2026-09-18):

# Plan 2 — one sunny half-day

**This is the most valuable half-day you can give us.** It is the only plan that measures what the
solar charge hardware actually does, and that is the one thing we cannot work out from here.

## Is this the right plan for you?

Yes, if you have **sun on the panel**, a **multimeter**, and about **an hour and a half**.

Do [Plan 1](plan-bench.md) first if you can. If you cannot — if this is your only session with the
board — then do Part A out of it first, so the board is running and you can see its page, and skip
the rest.

**Morning is much better than afternoon.** The test needs a battery that is *not already full*: a
full battery will not take charge however hard we ask it to, and the measurements will all come
out the same and tell us nothing.

## What you need

- The board running, with its page open on a phone or laptop — [Part A](../TESTING.md#part-a--getting-it-running).
- The solar panel connected, in the sun, with as little moving cloud as you can manage.
- The 12 V battery, **not fully charged**.
- A multimeter.

**Safety.** Disconnect the solar panel before you connect or disconnect anything else. A panel in
sunlight is live even when nothing is switched on, and you cannot turn it off — only cover it or
unplug it. And do not disconnect the battery while the panel is connected: the battery is what
absorbs the panel's power, and without it the charge circuit has nowhere to put it.

## The order

| | Section | About | Needs |
|---|---|---|---|
| 1 | [Step G1](../TESTING.md#step-g1--the-solar-panel-voltage) | is the panel voltage it reports correct | 15 min |
| 2 | [Part H](../TESTING.md#part-h--setting-the-charger-by-hand) | working the charger by hand, 0 to 255 | 45 min |

That is all. Two things, and the second one is the point of the exercise.

**Part H cannot harm the battery.** Every setting it asks you to try draws the same charging
current as now, or less. Nothing in it can overcharge anything. If at any moment you are
uncomfortable, set the number back to **255**, which is the gentlest setting, and stop.

**Do not go on to Part I** in this session. Part I lets the board charge on its own, unattended,
and it should not be switched on until someone has looked at your Part H numbers. It is
[Plan 3](plan-long-run.md).

## What we are actually asking

Our software sets charging by sending the hardware a number from 0 to 255. We believe 0 asks for
the most charging and 255 for the least — backwards from what anyone would expect — but we have
never been able to check it, because we have never had the board.

So the numbers you write down in [Step H2](../TESTING.md#step-h2--work-through-the-settings) are
not a formality. They are how we find out whether our idea of this hardware is right at all. A
table of eight readings from you settles a question we have otherwise had to guess at.

**Please write down the actual numbers**, including any that look wrong to you. A reading that
looks wrong is more useful than one that looks right, because it usually points straight at which
part of the software is mistaken.

## When you have finished

Send back what [How to report what you find](../TESTING.md#how-to-report-what-you-find) asks for.
For this plan especially, send the whole table from Step H2 even if you did not finish it.

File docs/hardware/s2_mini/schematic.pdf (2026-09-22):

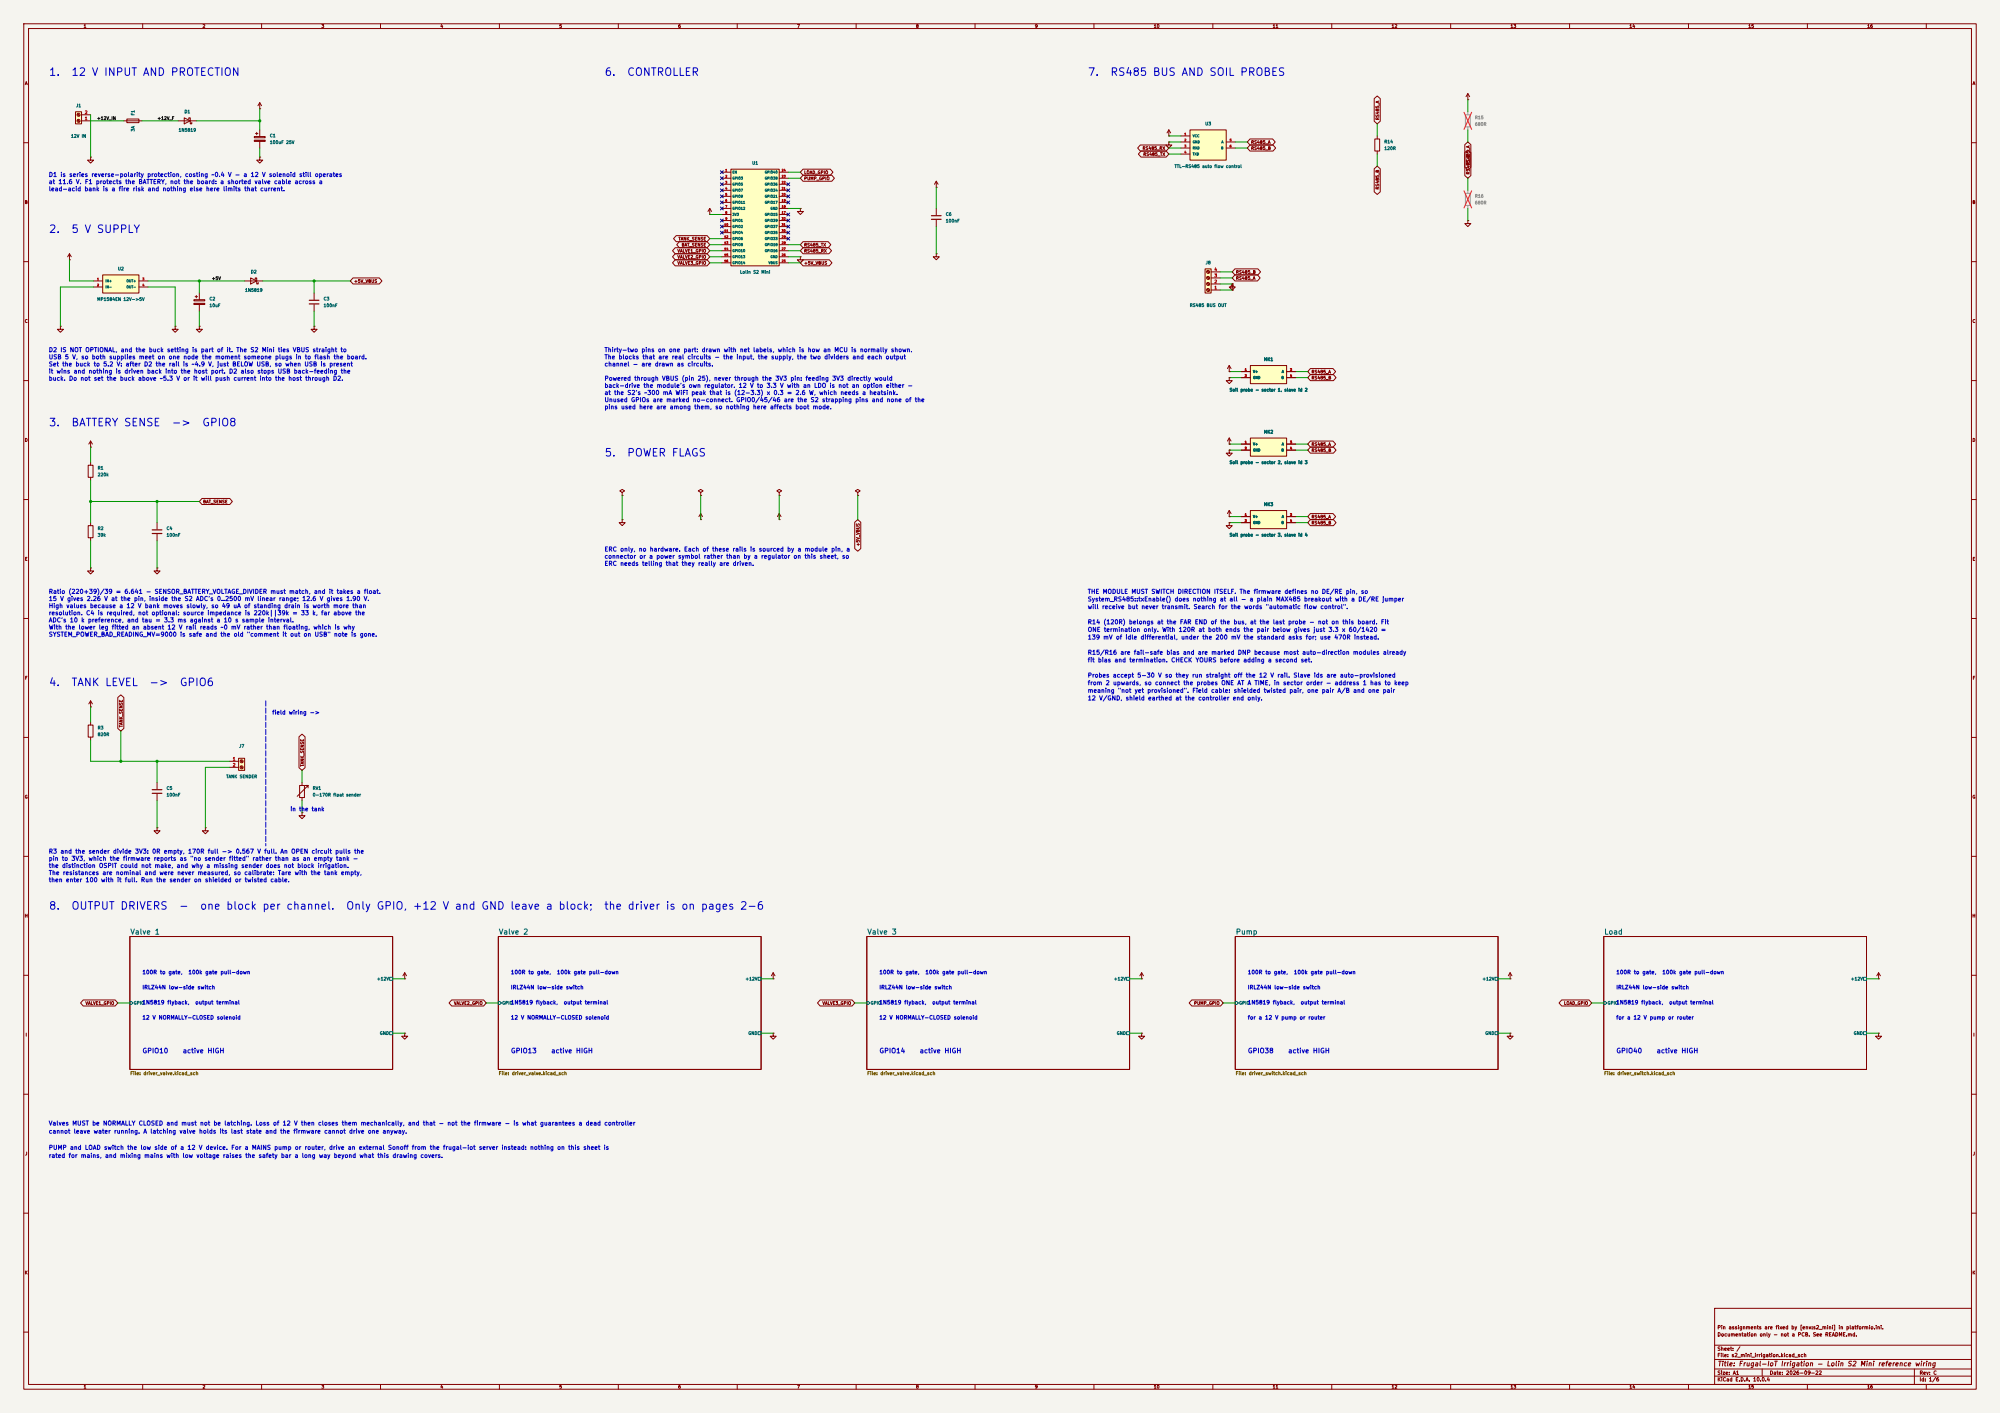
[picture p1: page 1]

7. RS485 BUS AND SOIL PROBES
LOAD_GPIO RS485_A

at 11.6 V. F1 protects the BATTERY, not the board: a shorted valve cable across a D1 is series reverse-polarity protection, costing ~0.4 V - a 12 V solenoid still operates

lead-acid bank is a fire risk and nothing else here limits that current.

ERC only, no hardware. Each of these rails is sourced by a module pin, a D2 IS NOT OPTIONAL, and the buck setting is part of it. The S2 Mini ties VBUS straight to
USB 5 V, so both supplies meet on one node the moment someone plugs in to flash the board.
Set the buck to 5.2 V: after D2 the rail is ~4.9 V, just BELOW USB, so when USB is present
it wins and nothing is driven back into the host port. D2 also stops USB back-feeding the
buck. Do not set the buck above ~5.3 V or it will push current into the host through D2.
BAT_SENSE TANK_SENSE

Thirty-two pins on one part: drawn with net labels, which is how an MCU is normally shown.
The blocks that are real circuits - the input, the supply, the two dividers and each output
channel - are drawn as circuits.

Powered through VBUS (pin 25), never through the 3V3 pin: feeding 3V3 directly would
back-drive the module's own regulator. 12 V to 3.3 V with an LDO is not an option either -
at the S2's ~300 mA WiFi peak that is (12-3.3) x 0.3 = 2.6 W, which needs a heatsink.
Unused GPIOs are marked no-connect. GPIO0/45/46 are the S2 strapping pins and none of the
pins used here are among them, so nothing here affects boot mode.

Soil probe - sector 1, slave id 2

Soil probe - sector 2, slave id 3

Soil probe - sector 3, slave id 4 R3

Soil probe - sector 3, slave id 4

connector or a power symbol rather than by a regulator on this sheet, so
ERC needs telling that they really are driven.

Ratio (220+39)/39 = 6.641 - SENSOR_BATTERY_VOLTAGE_DIVIDER must match, and it takes a float.
15 V gives 2.26 V at the pin, inside the S2 ADC's 0..2500 mV linear range; 12.6 V gives 1.90 V.
High values because a 12 V bank moves slowly, so 49 uA of standing drain is worth more than
resolution. C4 is required, not optional: source impedance is 220k||39k = 33 k, far above the
ADC's 10 k preference, and tau = 3.3 ms against a 10 s sample interval.
With the lower leg fitted an absent 12 V rail reads ~0 mV rather than floating, which is why
SYSTEM_POWER_BAD_READING_MV=9000 is safe and the old "comment it out on USB" note is gone.

THE MODULE MUST SWITCH DIRECTION ITSELF. The firmware defines no DE/RE pin, so
System_RS485::txEnable() does nothing at all - a plain MAX485 breakout with a DE/RE jumper
will receive but never transmit. Search for the words "automatic flow control".

R14 (120R) belongs at the FAR END of the bus, at the last probe - not on this board. Fit
ONE termination only. With 120R at both ends the pair below gives just 3.3 x 60/1420 =
139 mV of idle differential, under the 200 mV the standard asks for; use 470R instead.

R15/R16 are fail-safe bias and are marked DNP because most auto-direction modules already
fit bias and termination. CHECK YOURS before adding a second set.

Probes accept 5-30 V so they run straight off the 12 V rail. Slave ids are auto-provisioned
from 2 upwards, so connect the probes ONE AT A TIME, in sector order - address 1 has to keep
meaning "not yet provisioned". Field cable: shielded twisted pair, one pair A/B and one pair
12 V/GND, shield earthed at the controller end only.

R3 and the sender divide 3V3: 0R empty, 170R full -> 0.567 V full. An OPEN circuit pulls the
pin to 3V3, which the firmware reports as "no sender fitted" rather than as an empty tank -
the distinction OSPIT could not make, and why a missing sender does not block irrigation.
The resistances are nominal and were never measured, so calibrate: Tare with the tank empty,
then enter 100 with it full. Run the sender on shielded or twisted cable.

8. OUTPUT DRIVERS - one block per channel. Only GPIO, +12 V and GND leave a block; the driver is on pages 2-6

100R to gate, 100k gate pull-down

for a 12 V pump or router

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

1 | 2 | 3 | 4 | 5 | 6

AB

C

D

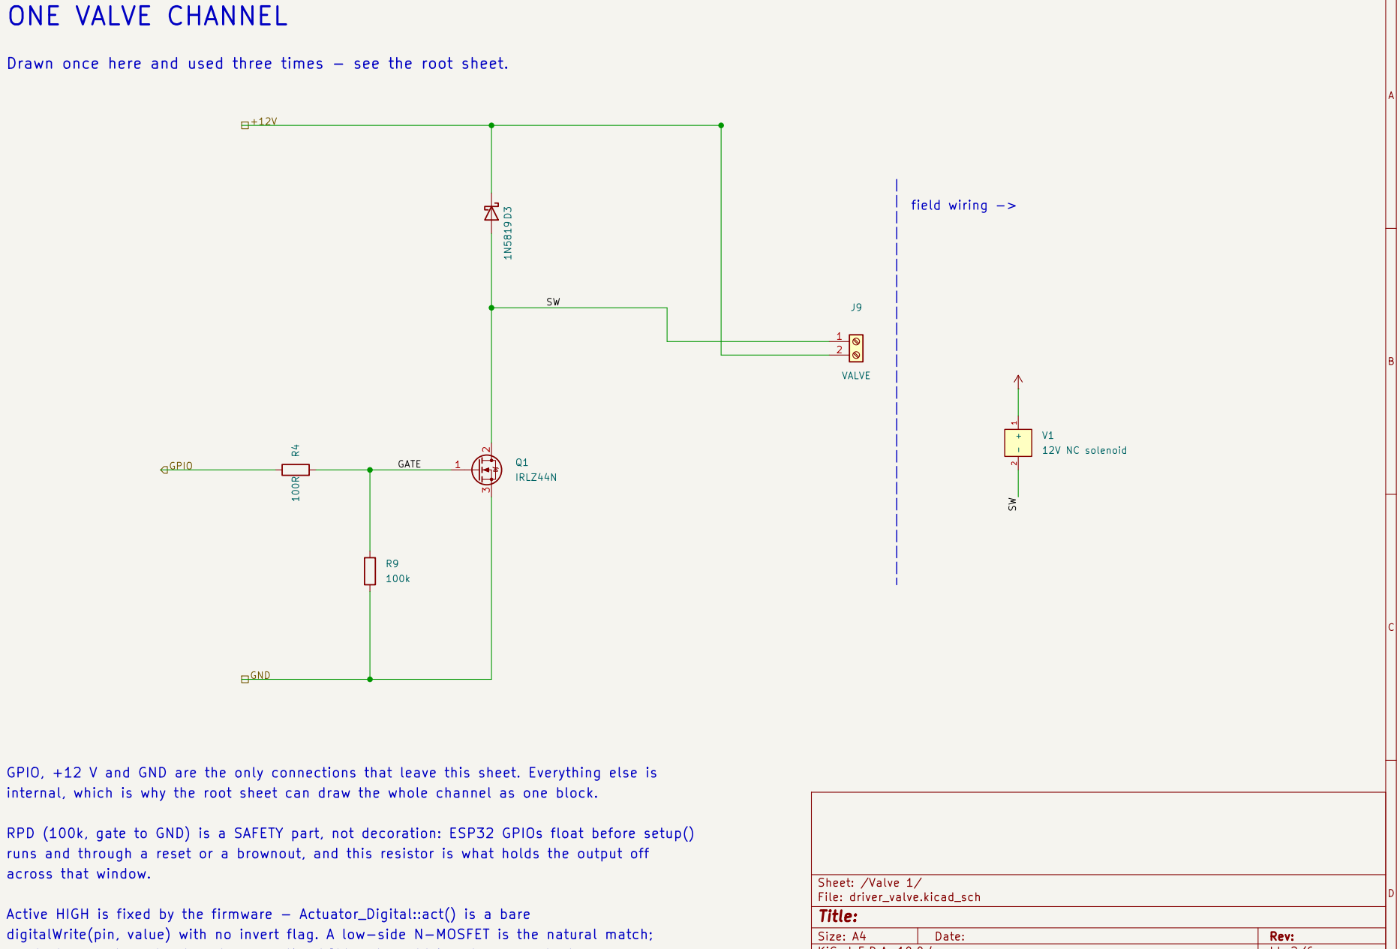
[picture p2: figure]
D Date:; Size: A4; Rev:; Title:; File: driver_valve.kicad_sch; Sheet: /Valve 1/ R4 100R; IRLZ44N; 1 - 2 V1 12V NC solenoid R9; VALVE GND; GPIO; GATE; field wiring -> ONE VALVE CHANNEL

Drawn once here and used three times - see the root sheet.

GPIO, +12 V and GND are the only connections that leave this sheet. Everything else is

D clamps the inductive kick when the FET turns off. Cathode to +12 V - backwards, it is a digitalWrite(pin, value) with no invert flag. A low-side N-MOSFET is the natural match; runs and through a reset or a brownout, and this resistor is what holds the output off

RPD (100k, gate to GND) is a SAFETY part, not decoration: ESP32 GPIOs float before setup() internal, which is why the root sheet can draw the whole channel as one block.

short across the supply the moment the output goes on. most cheap opto-relay boards are active LOW and would invert every output.

Active HIGH is fixed by the firmware - Actuator_Digital::act() is a bare across that window.

AB

C

D

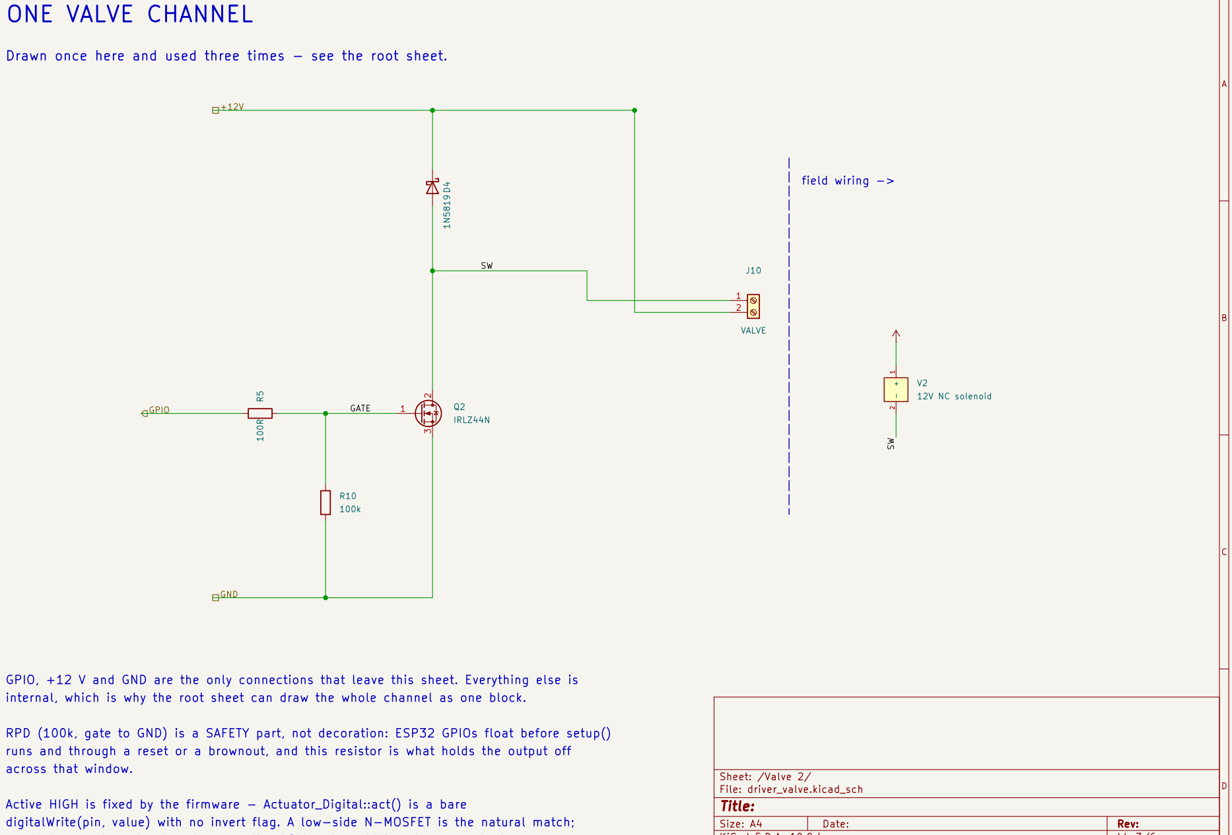
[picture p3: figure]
D Date:; Title:; File: driver_valve.kicad_sch; Sheet: /Valve 2/ R5 100R; IRLZ44N; 1 - 2 V2 12V NC solenoid R10; VALVE GND; GPIO; GATE; field wiring -> ONE VALVE CHANNEL

Drawn once here and used three times - see the root sheet.

GPIO, +12 V and GND are the only connections that leave this sheet. Everything else is

digitalWrite(pin, value) with no invert flag. A low-side N-MOSFET is the natural match; runs and through a reset or a brownout, and this resistor is what holds the output off

RPD (100k, gate to GND) is a SAFETY part, not decoration: ESP32 GPIOs float before setup() internal, which is why the root sheet can draw the whole channel as one block.

Active HIGH is fixed by the firmware - Actuator_Digital::act() is a bare across that window.

AB

C

D

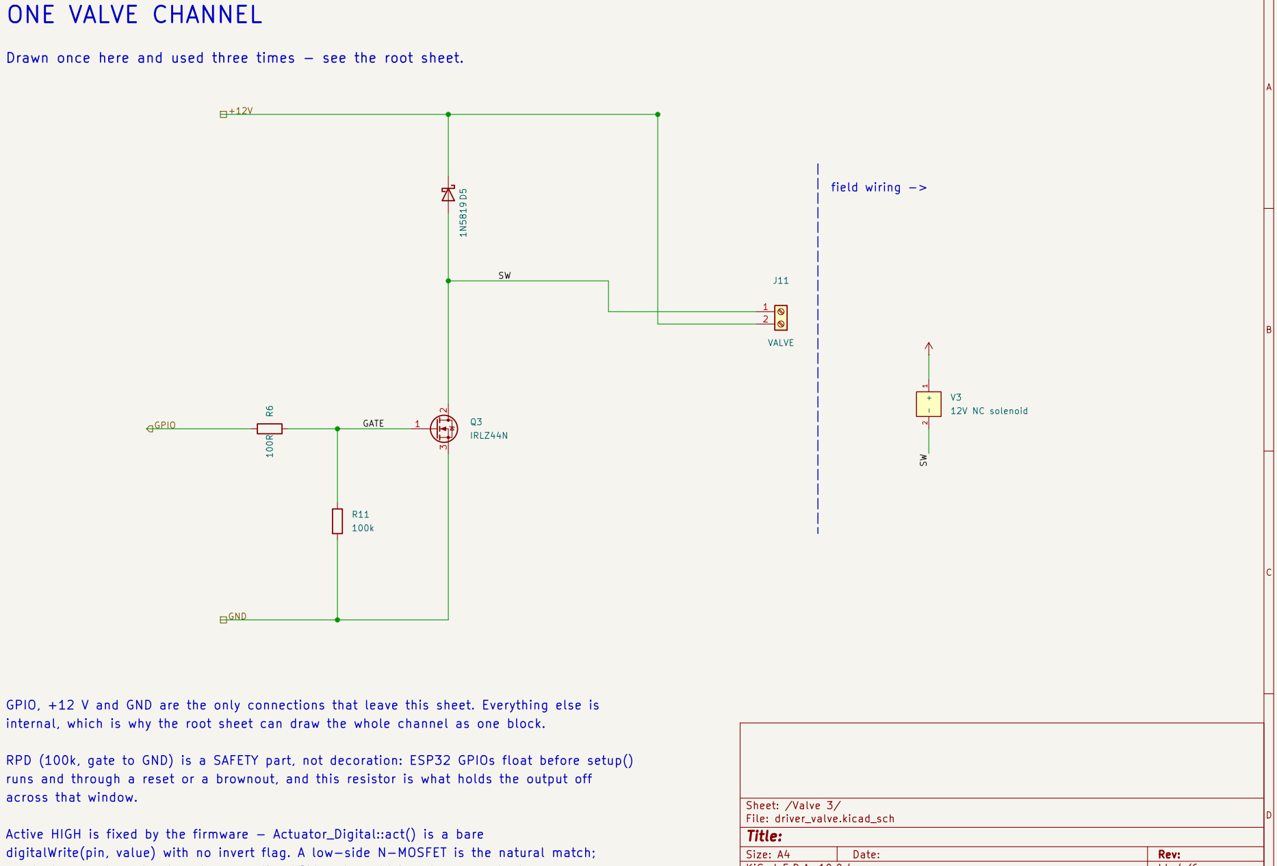
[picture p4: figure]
D Date:; Title:; File: driver_valve.kicad_sch; Sheet: /Valve 3/ R6 100R; IRLZ44N; 1 - 2 V3 12V NC solenoid R11; VALVE GND; GPIO; GATE; field wiring -> ONE VALVE CHANNEL

Drawn once here and used three times - see the root sheet.

GPIO, +12 V and GND are the only connections that leave this sheet. Everything else is

digitalWrite(pin, value) with no invert flag. A low-side N-MOSFET is the natural match; runs and through a reset or a brownout, and this resistor is what holds the output off

RPD (100k, gate to GND) is a SAFETY part, not decoration: ESP32 GPIOs float before setup() internal, which is why the root sheet can draw the whole channel as one block.

Active HIGH is fixed by the firmware - Actuator_Digital::act() is a bare across that window.

AB

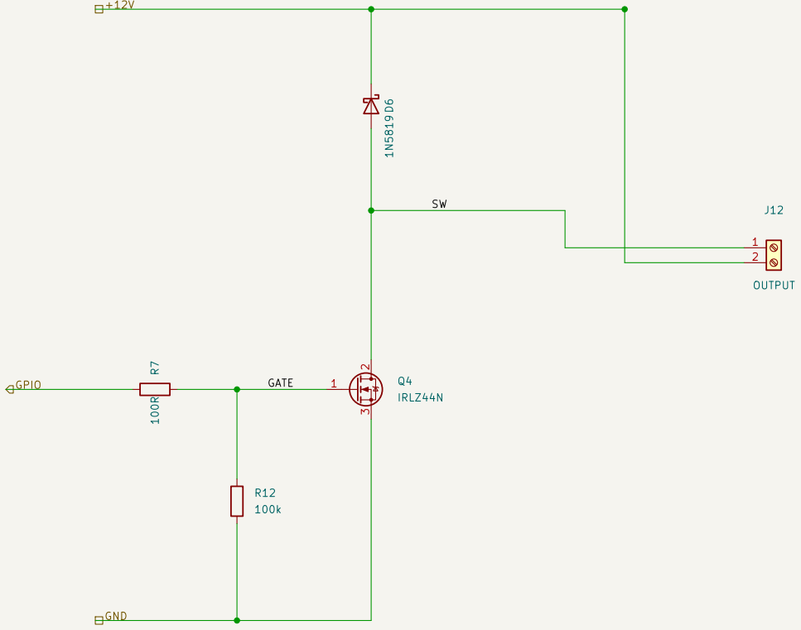
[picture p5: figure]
J12 OUTPUT D6 1N5819 R7 100R; IRLZ44N; GND

C

D

AB

C

D Date:

### Title:

File: driver_switch.kicad_sch

Sheet: /Pump/

GPIO | +12V | GATE | SW Active HIGH is fixed by the firmware - Actuator_Digital::act() is a bare

digitalWrite(pin, value) with no invert flag. A low-side N-MOSFET is the natural match;

D clamps the inductive kick when the FET turns off. Cathode to +12 V - backwards, it is a Switches the low side of a 12 V device. For a MAINS pump or router use an external

GPIO, +12 V and GND are the only connections that leave this sheet. Everything else is

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

short across the supply the moment the output goes on. most cheap opto-relay boards are active LOW and would invert every output. across that window.

Drawn once here and used twice times - see the root sheet.

# ONE PUMP / LOAD CHANNEL

field wiring ->

AB

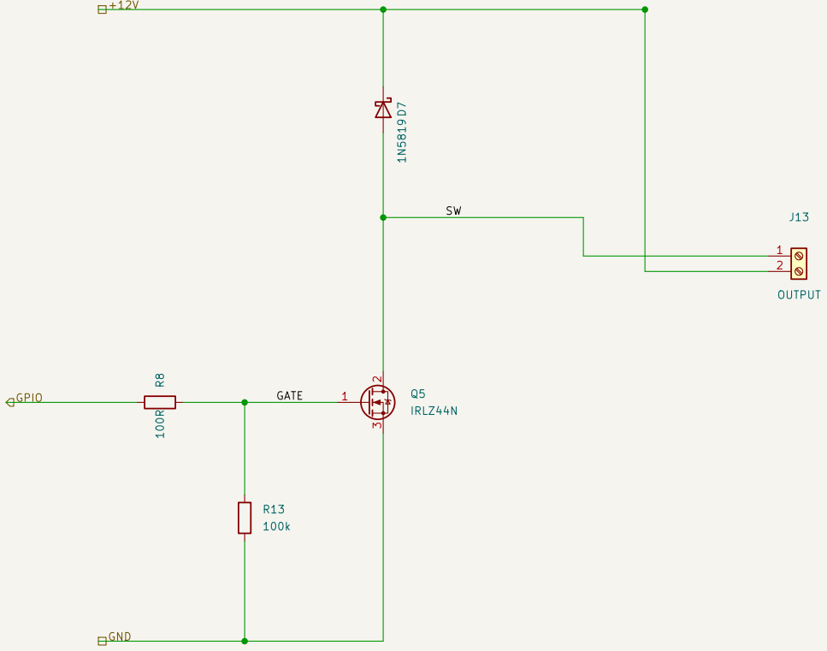
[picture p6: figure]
J13 OUTPUT D7 1N5819 R8 100R; IRLZ44N; GND

C

D

AB

C

D Date:

### Title:

File: driver_switch.kicad_sch

Sheet: /Load/

GPIO | +12V | GATE | SW Active HIGH is fixed by the firmware - Actuator_Digital::act() is a bare

digitalWrite(pin, value) with no invert flag. A low-side N-MOSFET is the natural match;

D clamps the inductive kick when the FET turns off. Cathode to +12 V - backwards, it is a Switches the low side of a 12 V device. For a MAINS pump or router use an external

GPIO, +12 V and GND are the only connections that leave this sheet. Everything else is

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

short across the supply the moment the output goes on. most cheap opto-relay boards are active LOW and would invert every output. across that window.

Drawn once here and used twice times - see the root sheet.

# ONE PUMP / LOAD CHANNEL

field wiring ->

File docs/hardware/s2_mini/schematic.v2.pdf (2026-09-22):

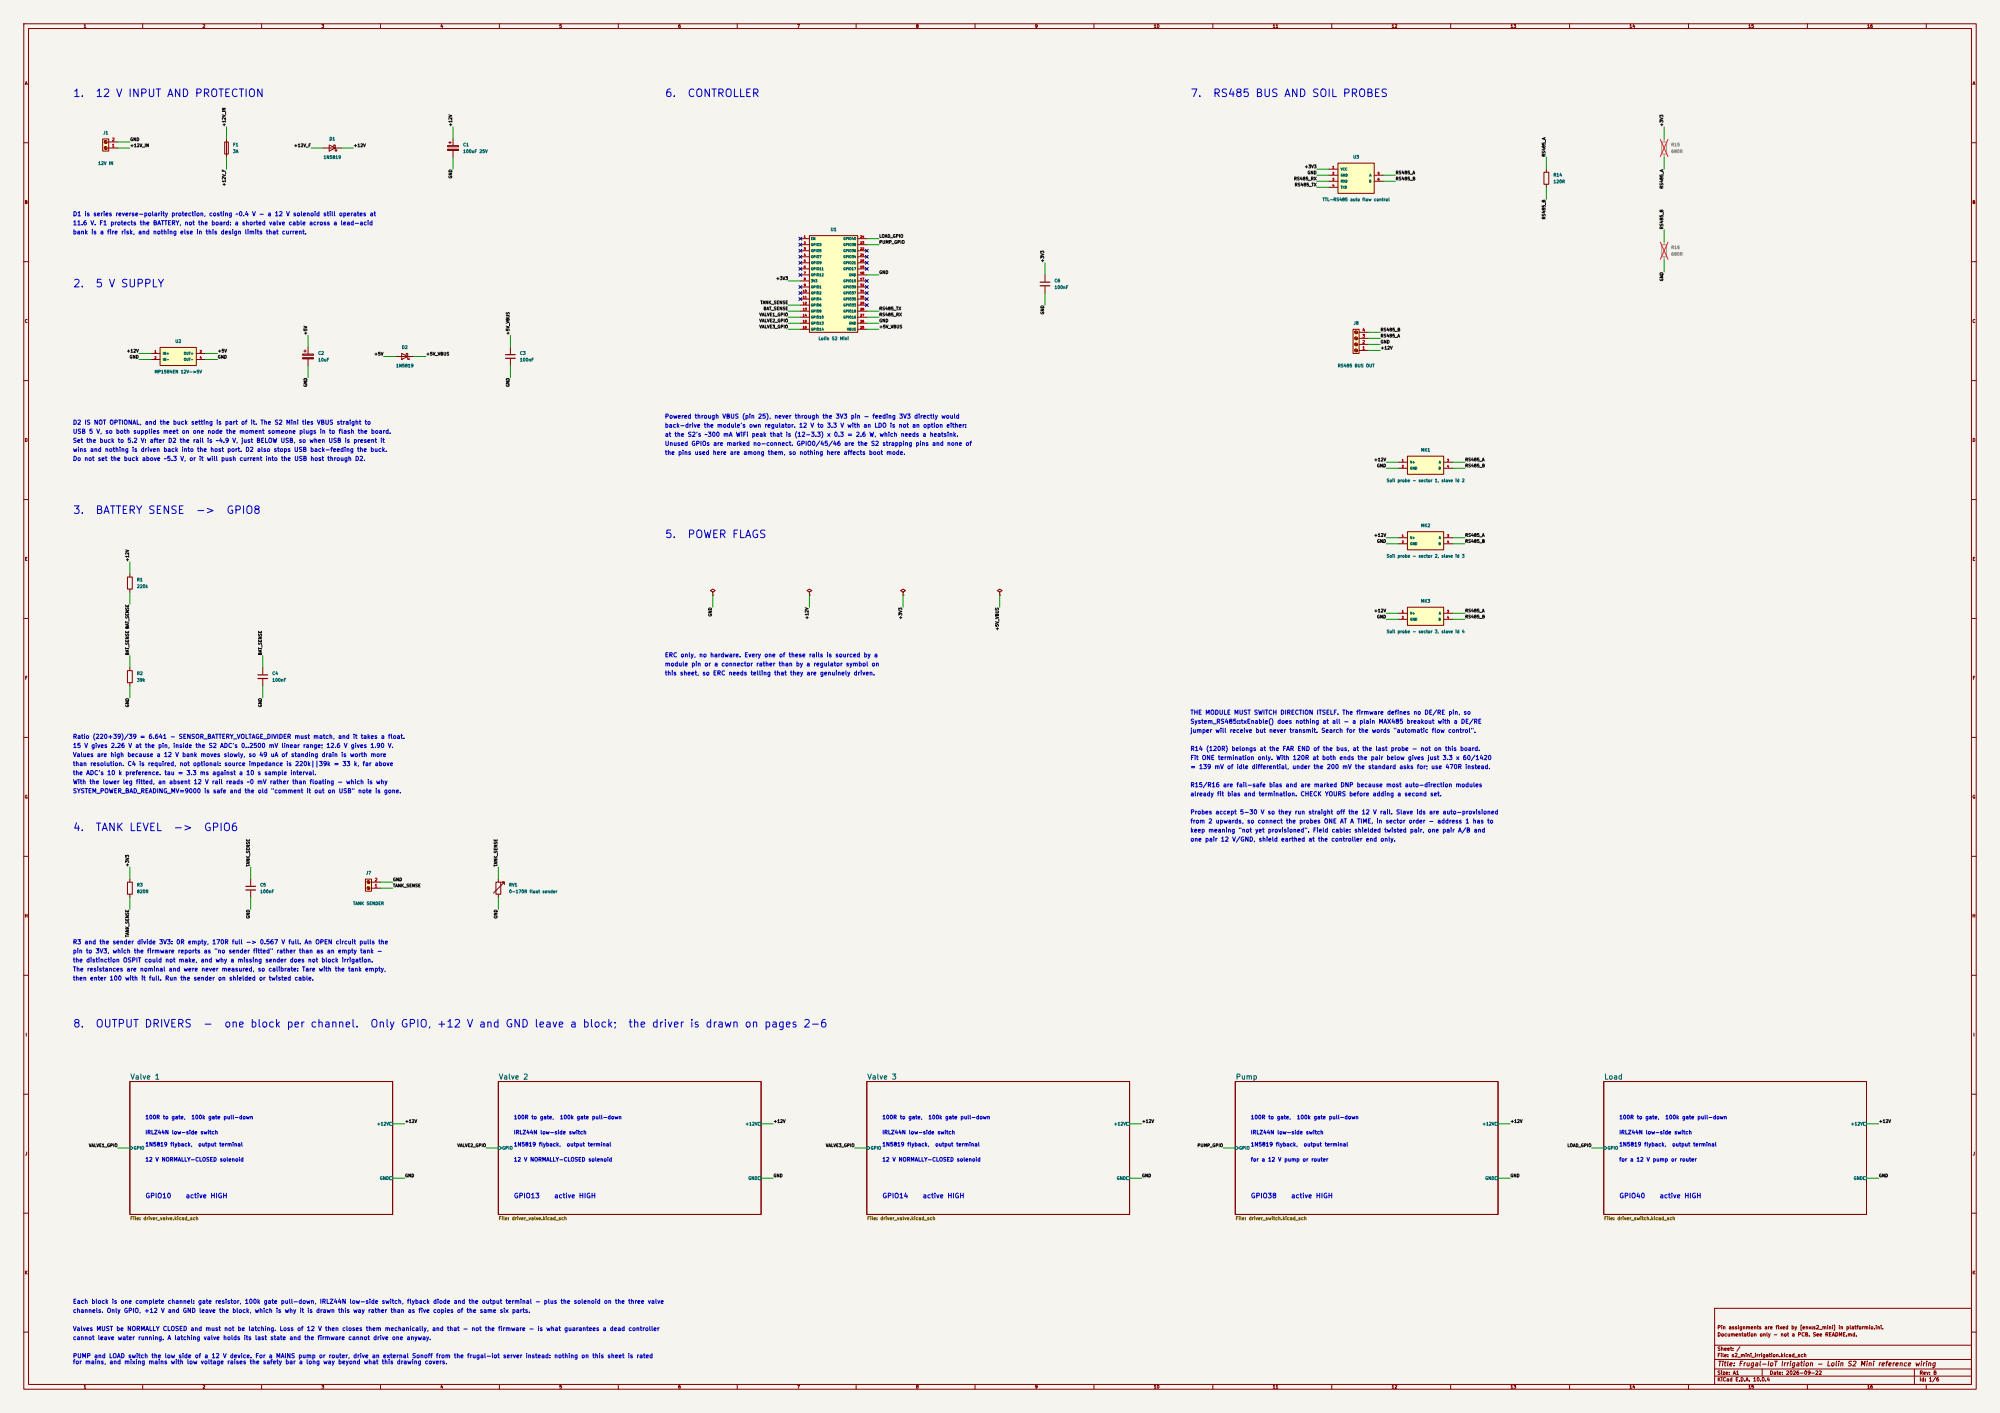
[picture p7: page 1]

7. RS485 BUS AND SOIL PROBES
TTL-RS485 auto flow control 1

D1 is series reverse-polarity protection, costing ~0.4 V - a 12 V solenoid still operates at
11.6 V. F1 protects the BATTERY, not the board: a shorted valve cable across a lead-acid
bank is a fire risk, and nothing else in this design limits that current.
GND TANK_SENSE +3V3
VALVE2_GPIO GND

Soil probe - sector 2, slave id 3 D2

Powered through VBUS (pin 25), never through the 3V3 pin - feeding 3V3 directly would

D2 IS NOT OPTIONAL, and the buck setting is part of it. The S2 Mini ties VBUS straight to
USB 5 V, so both supplies meet on one node the moment someone plugs in to flash the board.
Set the buck to 5.2 V: after D2 the rail is ~4.9 V, just BELOW USB, so when USB is present it
wins and nothing is driven back into the host port. D2 also stops USB back-feeding the buck.
Do not set the buck above ~5.3 V, or it will push current into the USB host through D2.

back-drive the module's own regulator. 12 V to 3.3 V with an LDO is not an option either:
at the S2's ~300 mA WiFi peak that is (12-3.3) x 0.3 = 2.6 W, which needs a heatsink.
Unused GPIOs are marked no-connect. GPIO0/45/46 are the S2 strapping pins and none of
the pins used here are among them, so nothing here affects boot mode.

Soil probe - sector 1, slave id 2

Soil probe - sector 3, slave id 4 RV1

ERC only, no hardware. Every one of these rails is sourced by a
module pin or a connector rather than by a regulator symbol on
this sheet, so ERC needs telling that they are genuinely driven.

THE MODULE MUST SWITCH DIRECTION ITSELF. The firmware defines no DE/RE pin, so System_RS485::txEnable() does nothing at all - a plain MAX485 breakout with a DE/RE

jumper will receive but never transmit. Search for the words "automatic flow control".

Ratio (220+39)/39 = 6.641 - SENSOR_BATTERY_VOLTAGE_DIVIDER must match, and it takes a float.
15 V gives 2.26 V at the pin, inside the S2 ADC's 0..2500 mV linear range; 12.6 V gives 1.90 V.
Values are high because a 12 V bank moves slowly, so 49 uA of standing drain is worth more
than resolution. C4 is required, not optional: source impedance is 220k||39k = 33 k, far above
the ADC's 10 k preference. tau = 3.3 ms against a 10 s sample interval.
With the lower leg fitted, an absent 12 V rail reads ~0 mV rather than floating - which is why
SYSTEM_POWER_BAD_READING_MV=9000 is safe and the old "comment it out on USB" note is gone.

R14 (120R) belongs at the FAR END of the bus, at the last probe - not on this board.
Fit ONE termination only. With 120R at both ends the pair below gives just 3.3 x 60/1420

R15/R16 are fail-safe bias and are marked DNP because most auto-direction modules
already fit bias and termination. CHECK YOURS before adding a second set.

Probes accept 5-30 V so they run straight off the 12 V rail. Slave ids are auto-provisioned
from 2 upwards, so connect the probes ONE AT A TIME, in sector order - address 1 has to
keep meaning "not yet provisioned". Field cable: shielded twisted pair, one pair A/B and
one pair 12 V/GND, shield earthed at the controller end only.

R3 and the sender divide 3V3: 0R empty, 170R full -> 0.567 V full. An OPEN circuit pulls the
pin to 3V3, which the firmware reports as "no sender fitted" rather than as an empty tank -

The resistances are nominal and were never measured, so calibrate: Tare with the tank empty,
then enter 100 with it full. Run the sender on shielded or twisted cable.

8. OUTPUT DRIVERS - one block per channel. Only GPIO, +12 V and GND leave a block; the driver is drawn on pages 2-6

100R to gate, 100k gate pull-down

for a 12 V pump or router

Each block is one complete channel: gate resistor, 100k gate pull-down, IRLZ44N low-side switch, flyback diode and the output terminal - plus the solenoid on the three valve
channels. Only GPIO, +12 V and GND leave the block, which is why it is drawn this way rather than as five copies of the same six parts.

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

1 | 2 | 3 | 4 | 5 | 6

AB

C

D

AB

C

D Date:

Size: A4 | Rev:

## Title:

File: driver_valve.kicad_sch

Sheet: /Valve 1/

1

2

J9
VALVE D3 1N5819 R4 100R R9 100k

+

1 -
2 V1

12V NC solenoid 1

2 3 Q1

IRLZ44N | +12V

GPIO

GND

GATE | SW | +12V | SW+12V GATE | SW SW GND

GATE GPIO, +12 V and GND are the only connections that leave this sheet - everything else

### RPD (100k, gate to GND) is a SAFETY part, not decoration: ESP32 GPIOs float before

is internal, which is why the root sheet can show the channel as a single block.

shuts it mechanically, which is what makes a dead controller safe.

The solenoid MUST be normally closed and must not be latching - loss of 12 V then match; most cheap opto-relay boards are active LOW and would invert every output.

digitalWrite(pin, value) with no invert flag. A low-side N-MOSFET is the natural

Active HIGH is fixed by the firmware - Actuator_Digital::act() is a bare

output off across that window.

setup() runs and through a reset or brownout, and this resistor is what holds the

# ONE VALVE CHANNEL - drawn once, used three times

AB

C

D

AB

C

D Date:

## Title:

File: driver_valve.kicad_sch

Sheet: /Valve 2/

1

2

J10
VALVE D4 1N5819 R5 100R R10 100k

+

1 -
2 V2

12V NC solenoid 1

2 3 Q2

IRLZ44N | +12V

GPIO

GND

GATE | SW | +12V | SW+12V GATE | SW SW GND

GATE GPIO, +12 V and GND are the only connections that leave this sheet - everything else

### RPD (100k, gate to GND) is a SAFETY part, not decoration: ESP32 GPIOs float before

is internal, which is why the root sheet can show the channel as a single block.

shuts it mechanically, which is what makes a dead controller safe.

The solenoid MUST be normally closed and must not be latching - loss of 12 V then match; most cheap opto-relay boards are active LOW and would invert every output.

digitalWrite(pin, value) with no invert flag. A low-side N-MOSFET is the natural

Active HIGH is fixed by the firmware - Actuator_Digital::act() is a bare

output off across that window.

setup() runs and through a reset or brownout, and this resistor is what holds the

# ONE VALVE CHANNEL - drawn once, used three times

AB

C

D

AB

C

D Date:

## Title:

File: driver_valve.kicad_sch

Sheet: /Valve 3/

1

2

J11
VALVE D5 1N5819 R6 100R R11 100k

+

1 -
2 V3

12V NC solenoid 1

2 3 Q3

IRLZ44N | +12V

GPIO

GND

GATE | SW | +12V | SW+12V GATE | SW SW GND

GATE GPIO, +12 V and GND are the only connections that leave this sheet - everything else

### RPD (100k, gate to GND) is a SAFETY part, not decoration: ESP32 GPIOs float before

is internal, which is why the root sheet can show the channel as a single block.

shuts it mechanically, which is what makes a dead controller safe.

The solenoid MUST be normally closed and must not be latching - loss of 12 V then match; most cheap opto-relay boards are active LOW and would invert every output.

digitalWrite(pin, value) with no invert flag. A low-side N-MOSFET is the natural

Active HIGH is fixed by the firmware - Actuator_Digital::act() is a bare

output off across that window.

setup() runs and through a reset or brownout, and this resistor is what holds the

# ONE VALVE CHANNEL - drawn once, used three times

AB

C

D

AB

C

D Date:

## Title:

File: driver_switch.kicad_sch

Sheet: /Pump/ R12 100k R7 100R | D6 1N5819 1
2 3 Q4

IRLZ44N

1

2

J12 OUTPUT GND

GPIO | +12V | +12V GND | SW
GATE | GATE | SW
GATE | SW

is internal, which is why the root sheet can show the channel as a single block.

### RPD (100k, gate to GND) is a SAFETY part, not decoration: ESP32 GPIOs float before

GPIO, +12 V and GND are the only connections that leave this sheet - everything else

Sonoff: nothing here is rated for mains.

Switches the low side of a 12 V device. For a MAINS pump or router use an external match; most cheap opto-relay boards are active LOW and would invert every output.

digitalWrite(pin, value) with no invert flag. A low-side N-MOSFET is the natural

Active HIGH is fixed by the firmware - Actuator_Digital::act() is a bare

output off across that window.

setup() runs and through a reset or brownout, and this resistor is what holds the

# ONE PUMP / LOAD CHANNEL - drawn once, used two times

AB

C

D

AB

C

D Date:

## Title:

File: driver_switch.kicad_sch

Sheet: /Load/ R13 100k R8 100R | D7 1N5819 1
2 3 Q5

IRLZ44N

1

2

J13 OUTPUT GND

GPIO | +12V | +12V GND | SW
GATE | GATE | SW
GATE | SW

is internal, which is why the root sheet can show the channel as a single block.

### RPD (100k, gate to GND) is a SAFETY part, not decoration: ESP32 GPIOs float before

GPIO, +12 V and GND are the only connections that leave this sheet - everything else

Sonoff: nothing here is rated for mains.

Switches the low side of a 12 V device. For a MAINS pump or router use an external match; most cheap opto-relay boards are active LOW and would invert every output.

digitalWrite(pin, value) with no invert flag. A low-side N-MOSFET is the natural

Active HIGH is fixed by the firmware - Actuator_Digital::act() is a bare

output off across that window.

setup() runs and through a reset or brownout, and this resistor is what holds the

# ONE PUMP / LOAD CHANNEL - drawn once, used two times

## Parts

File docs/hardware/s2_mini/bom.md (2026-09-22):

# Bill of materials — S2 Mini irrigation node

Prices are indicative AliExpress (Sept 2026), seach terms provided.

[`bom.csv`](bom.csv) is machine-generated version without sourcing.

## Read these three lines before ordering

1. **Valves must be NORMALLY CLOSED and must not be latching.** This is a safety requirement, not
   a preference — see "Failure modes" in [README.md](README.md). A latching valve cannot be driven
   by this firmware at all.
2. **The RS485 module must have hardware automatic flow control.** The firmware defines no DE/RE
   pin. Search for those exact words; a plain MAX485 breakout with a DE/RE jumper will receive but
   never transmit.
3. **Do not substitute an opto-isolated relay board** for the MOSFET drivers unless you check its
   polarity. The firmware is active HIGH and no invert flag exists; most of those boards are
   active LOW.

## Controller

| Qty | Part | Designators | ~Each | Search for |
|---:|---|---|---:|---|
| 1 | Lolin / Wemos S2 Mini (ESP32-S2, 4 MB flash, 2 MB PSRAM) | U1 | $5.00 | `Lolin S2 Mini ESP32-S2` |
| 1 | DC-DC buck module, adjustable, 3 A | U2 | $0.65 | `MP1584EN mini buck converter adjustable` |
| 1 | TTL↔RS485 module, **hardware automatic flow control**, 3.3/5 V | U3 | $0.40 | `TTL to RS485 automatic flow control 3.3V 5V` |
| 5 | Logic-level N-MOSFET, TO-220 | Q1–Q5 | $0.35 | `IRLZ44N` |
| 7 | Schottky diode, 1 A 40 V | D1–D7 | $0.05 | `1N5819` |
| 1 | Blade fuse holder + 3 A fuse | F1 | $0.50 | `inline blade fuse holder 12V` |
| 5 | 100 Ω resistor, ¼ W | R4–R8 | | `1/4W metal film resistor kit` |
| 5 | 100 kΩ resistor, ¼ W | R9–R13 | | (from the same kit) |
| 1 | 220 kΩ, 1 % | R1 | | (from the same kit) |
| 1 | 39 kΩ, 1 % | R2 | | (from the same kit) |
| 1 | 820 Ω | R3 | | (from the same kit) |
| 1 | 120 Ω — bus termination, fit at the **last probe** | R14 | | (from the same kit) |
| 2 | 680 Ω — fail-safe bias, **usually not needed** | R15, R16 | | (from the same kit) |
| 1 | 100 µF 25 V electrolytic | C1 | $0.05 | `100uF 25V electrolytic capacitor` |
| 1 | 10 µF electrolytic | C2 | $0.03 | (from a capacitor kit) |
| 4 | 100 nF ceramic | C3–C6 | $0.02 | (from a capacitor kit) |
| 7 | 2-way screw terminal, 5 mm pitch | J1, J7, J9–J13 | $0.10 | `KF301 2P screw terminal 5mm` |
| 1 | 4-way screw terminal, 5 mm pitch | J8 | $0.15 | `KF301 4P screw terminal 5mm` |
| 1 | Prototype board, ~7 × 9 cm | — | $0.50 | `double sided prototype PCB 7x9` |

**Controller subtotal: roughly $9**, assuming you already own resistor and capacitor kits — which
is the usual case, and why they are priced as kits rather than per part.

R15 and R16 are marked DNP on the schematic. Buy them (they cost nothing in a kit) but fit them
only after checking whether your RS485 module already has bias resistors.

## Per sector

| Qty | Part | ~Each | Search for |
|---:|---|---|---:|---|
| 1 | RS485 / Modbus-RTU soil moisture + temperature probe, IP68, 5–30 V | $16.00 | `RS485 Modbus soil moisture temperature sensor IP68` |
| 1 | **Normally-closed** 12 V DC solenoid valve, ½" or ¾" | $5–9 | `12V DC normally closed solenoid valve 1/2 irrigation` |

Three sectors as drawn: about **$65**. The probes dominate the cost of the whole node.

The reference probe is the DFRobot SEN0600; the generic equivalents on AliExpress use the same
register map (function 0x03, moisture then temperature) and are a third of the price. Anything
that answers Modbus RTU with those two registers will work.

## Optional

| Qty | Part | ~Each | Search for |
|---:|---|---|---:|---|
| 1 | Resistive float level sender, 0–170 Ω | $5–12 | `resistive water tank level sender 0-190 ohm` |
| 1 | 12 V pump, or a Sonoff for a mains one | — | `Sonoff basic R2` |
| — | Shielded twisted pair, 2 pair, 24 AWG | per m | `2 pair shielded twisted pair cable 24AWG` |

Senders are commonly sold as 0–190 Ω for fuel tanks, which works — the exact resistance does not
matter because the firmware is calibrated by Tare/Calibrate from the portal, not by the nominal
value. `SENSOR_TANK_RAW_FULL` can also be set in `platformio.ini` if you would rather not calibrate
by hand.

## Not needed, deliberately

- **No relay board.** Discrete MOSFETs are cheaper, silent, draw no holding current and match the
  firmware's polarity. See README.
- **No RS485 termination at the controller.** One 120 Ω at the far end of the bus only.
- **No separate probe supply.** The probes take 5–30 V and run from the 12 V rail.
- **No charge controller, panel or MPPT hardware.** Out of scope for this drawing; that is what
  the FF-ESP32-OpenMPPT build is for.
- **Nothing mains-rated.** A mains pump or router goes behind an external Sonoff.

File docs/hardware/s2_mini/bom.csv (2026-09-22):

Refs | Value | Qty | DNP
C1 | 100uF 25V | 1
C2 | 10uF | 1
C3-C6 | 100nF | 4
D1-D7 | 1N5819 | 7
F1 | 3A | 1
J1 | 12V IN | 1
J7 | TANK SENDER | 1
J8 | RS485 BUS OUT | 1
J9-J11 | VALVE | 3
J12,J13 | OUTPUT | 2
MK1 | Soil probe - sector 1, slave id 2 | 1
MK2 | Soil probe - sector 2, slave id 3 | 1
MK3 | Soil probe - sector 3, slave id 4 | 1
Q1-Q5 | IRLZ44N | 5
R1 | 220k | 1
R2 | 39k | 1
R3 | 820R | 1
R4-R8 | 100R | 5
R9-R13 | 100k | 5
R14 | 120R | 1
R15,R16 | 680R | 2 | DNP
RV1 | 0-170R float sender | 1
U1 | Lolin S2 Mini | 1
U2 | MP1584EN 12V->5V | 1
U3 | TTL-RS485 auto flow control | 1
V1-V3 | 12V NC solenoid | 3

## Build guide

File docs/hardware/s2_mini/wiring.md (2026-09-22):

# Wiring — Lolin S2 Mini irrigation node

This is the authoritative reference. [`schematic.pdf`](schematic.pdf) is the same information drawn
as a circuit; [`wiring.svg`](wiring.svg) is the same information drawn as a picture. If the three
ever disagree, believe this table — and run
[`check_wiring.py`](check_wiring.py), which compares it against both `platformio.ini` and the
schematic and exits non-zero if they have drifted.

**Read [README.md](README.md) before building anything.** It explains why the parts are what they
are, and three of the choices here are safety-relevant rather than merely tidy.

## Controller pins

Every row is fixed by `[env:s2_mini]` in [`platformio.ini`](../../../platformio.ini). The `Key`
column is what `check_wiring.py` matches on — don't rename it.

| Key | GPIO | S2 Mini pin | Direction | Connects to |
|---|---|---|---|---|
| valve1 | GPIO10 | 14 | out, active HIGH | R4 (100R) → Q1 gate |
| valve2 | GPIO13 | 15 | out, active HIGH | R5 (100R) → Q2 gate |
| valve3 | GPIO14 | 16 | out, active HIGH | R6 (100R) → Q3 gate |
| pump | GPIO38 | 23 | out, active HIGH | R7 (100R) → Q4 gate |
| load | GPIO40 | 24 | out, active HIGH | R8 (100R) → Q5 gate |
| tank | GPIO6 | 12 | analog in | junction of R3 (820R) and the float sender |
| rs485_rx | GPIO16 | 27 | UART in | RS485 module **RXD** |
| rs485_tx | GPIO18 | 28 | UART out | RS485 module **TXD** |
| battery | GPIO8 | 13 | analog in | junction of R1 (220k) and R2 (39k) |

Plus the supply and ground pins:

| S2 Mini pin | Name | Connects to |
|---|---|---|
| 25 | VBUS | D2 cathode (5 V from the buck, through the diode) |
| 8 | 3V3 | R3, RS485 module VCC, C6 — this pin is an **output** from the module's own regulator |
| 18, 26 | GND | common ground |

All 19 remaining GPIOs are unused and left unconnected.

## Power

| From | To | Notes |
|---|---|---|
| 12 V battery + | J1-1 | via the installation's own isolator if it has one |
| 12 V battery − | J1-2 | GND |
| J1-1 | F1 | 3 A fuse |
| F1 | D1 anode | 1N5819, series reverse-polarity protection |
| D1 cathode | **+12 V rail** | ~11.6 V after the diode drop |
| +12 V rail | U2 IN+ | buck module in |
| U2 OUT+ | D2 anode | **set the buck to 5.2 V** — see README |
| D2 cathode | S2 Mini VBUS (pin 25) | ~4.9 V |
| +12 V rail | C1 (100uF) | bulk, near the drivers |
| U2 OUT+ | C2 (10uF) | |
| VBUS rail | C3 (100nF) | |
| 3V3 | C6 (100nF) | |

## Each output channel, five times

Identical for valve 1–3, pump and load. `n` is the channel. This is what is inside each block on
page 1 of the schematic; it is drawn once on `driver_valve.kicad_sch` (valves) and
`driver_switch.kicad_sch` (pump and load).

| From | To |
|---|---|
| GPIO (table above) | gate resistor 100R |
| gate resistor | Q*n* gate **and** 100k pull-down to GND |
| Q*n* source | GND |
| Q*n* drain | terminal J-2, and flyback diode anode |
| flyback diode cathode | +12 V rail |
| terminal J-1 | +12 V rail |
| terminal J-1 / J-2 | the 12 V device (+ / −) |

The 100k pull-down is not optional — see README, "Failure modes".

## RS485 bus

| From | To |
|---|---|
| 3V3 | module VCC |
| GND | module GND |
| module RXD | GPIO16 |
| module TXD | GPIO18 |
| module A | J8-3 → every probe's A |
| module B | J8-4 → every probe's B |
| +12 V rail | J8-1 → every probe's V+ |
| GND | J8-2 → every probe's GND |

120R termination goes at the **far end** of the bus, across A and B at the last probe — not at the
module. Fit one only.

Field cable: shielded twisted pair, one pair for A/B and one for 12 V/GND, shield earthed at the
controller end only.

## Tank sender

| From | To |
|---|---|
| 3V3 | R3 (820R) |
| R3 | GPIO6, C5 (100nF) to GND, and J7-1 |
| J7-2 | GND |
| J7-1 / J7-2 | the float sender |

## Commissioning order

1. Fit the battery divider **before** first power-on, or comment `SENSOR_BATTERY_PIN` back out.
   A floating GPIO8 can read as a flat battery and put the board to sleep.
2. Set the buck to 5.2 V **off-load, before** connecting the S2 Mini.
3. Power up on 12 V with no probes and no valves. Check the portal appears.
4. Connect soil probes **one at a time, in sector order**, waiting a few read cycles between each.
   Addresses are auto-provisioned from 2 upwards and every probe ships as address 1, so two
   unprovisioned probes on the bus at once cannot be told apart.
5. Calibrate the tank: Tare with it empty, then enter `100` with it full.
6. Only then connect the valves.

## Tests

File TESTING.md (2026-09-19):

# Testing on real hardware

This guide is for the person who has the board in their hands. You do **not** need to understand
the software. Each step tells you what to do, what you should see, and what it means if you see
something else.

Please work through the steps **in order**. Each one depends on the ones before it. If a step
fails, stop there and report it — going on will only produce confusing results.

**You are probably not doing all of it.** Which Parts are worth your time depends on whether you
have sun, a multimeter, and how long you have the board for. Question 9 in
[HARDWARE-QUESTIONS.md](HARDWARE-QUESTIONS.md) has a table that picks one of
[docs/plan-bench.md](docs/plan-bench.md), [docs/plan-sunny-session.md](docs/plan-sunny-session.md)
or [docs/plan-long-run.md](docs/plan-long-run.md) for you. Each is a short list of which of the
Parts below to do, in which order. Start there rather than here.

## Before you start

**You need:**

- The board, and a USB cable that carries data (some charging cables carry power only — if the
  computer does not notice the board when you plug it in, try another cable).
- A multimeter.
- A phone or laptop with WiFi.
- A 12 V battery. A solar panel if you have one.
- The soil probes, valves, and the tank float sensor if you have them.

**You do not need** a laboratory power supply. Nothing here asks for one.

**Safety.** Disconnect the solar panel before you connect or disconnect anything else. A panel in
sunlight is live even when nothing is switched on, and you cannot turn it off — you can only cover
it or unplug it.

## How to report what you find

For each step, please send back:

- the **step number**
- what you saw
- any numbers you measured — please write down the **actual numbers**, not "about right"
- a photograph if anything looks physically different from what the step describes

Numbers that look wrong are much more useful to us than a description, because the wrong number
often tells us exactly which part of the software is mistaken.

---

# Part A — Getting it running

## Step A1 — Put the software on the board

If you build it yourself, see [README.md](README.md). Otherwise we will send you a file to flash.

**You should see:** the board's small light blinks, or the screen lights up, within a few seconds
of power being applied.

**If nothing happens:** check the USB cable first (see above), then tell us — do not continue.

## Step A2 — Connect to the board's own WiFi

The board makes its own WiFi network when it does not know any other one.

1. On your phone, look at the list of WiFi networks. One of them starts with `frugal-iot`, or possibly `ESP32`
2. Connect to it. There is no password.
3. A page should open by itself. If it does not, open a browser and type: `192.168.4.1`

**You should see:** a page listing the things the board can measure and control.

**If the page does not appear:** some phones quietly switch back to mobile data when a WiFi
network has no internet. Look for a message like "This network has no internet — stay connected?"
and choose to stay.

## Step A3 — Set the clock

Irrigation happens at a time of day, so the board has to know the time.

1. On that same page, find the line showing the date and time.
2. If it is wrong, or the year says 1970, press the **Set time** button. This copies the time from
   the phone you are holding.

**You should see:** the correct local date and time.

## Step A4 — Give it your WiFi (optional at this stage)

If there is WiFi where the board is, enter its name and password on the same page. The board will
then also appear on the dashboard and you can watch it from anywhere. Everything below works
without this.

---

# Part B — The outputs (valves, pump, load)

In this part you check that each output switches, and that the right output switches.

**Do this with the valves disconnected the first time.** You are testing the board, and a valve
that turns out to be wired to the wrong output is easier to find without water involved.

## Step B1 — Find the output terminals

Set your multimeter to measure **DC volts**. Put the black probe on the negative/ground terminal
of the battery, and the red probe on the output terminal you are testing.

## Step B2 — Switch each output on and off

On the board's page, find the section for each valve in turn: **Valve 1**, **Valve 2**,
**Valve 3**, and **Pump** if your board has one.

For each one:

1. Switch it **on**. Measure the voltage at its terminal. Write it down.
2. Switch it **off**. Measure again. Write it down.

**You should see:** roughly battery voltage (around 12 V) when on, and close to 0 V when off.

**Please record a table like this:**

| Output | Voltage when ON | Voltage when OFF |
|---|---|---|
| Valve 1 | | |
| Valve 2 | | |
| Valve 3 | | |
| Pump | | |

**Things that would be important to tell us:**

- Switching **Valve 1** on the page makes a **different** terminal turn on. That means the pin
  numbers in our software are wrong, and we need to know which one actually moved.
- An output is already on before you touch anything.
- An output never reaches battery voltage but sits at some middle value.

## Step B3 — Now connect one valve

Connect a single valve to output 1 and repeat step B2 for it. You should hear or feel it click.

**If the valve does not move but the voltage was correct in B2:** the valve needs more current
than the board can supply directly, and needs a relay between them. Tell us what the valve is.

---

# Part C — The soil probes

The probes talk to the board over a pair of wires shared by all of them. Each probe needs its own
**address** so the board can tell them apart. **Probes arrive from the factory all using the same
address (1).** If you connect two new probes at once, they both answer at the same time and the
board understands neither.

So the probes must be connected **one at a time**, in order.

## Step C1 — Connect the first probe only

Connect **one** probe to the RS485 terminals (often marked A and B, or D+ and D−). Leave the
others unconnected.

Wait about two minutes.

**You should see:** on the board's page, **Sector 1 probe** starts showing a moisture percentage
and a temperature.

**If nothing appears:** try swapping the two wires (A and B). Getting them the wrong way round is
very common and does no damage.

## Step C2 — Add the second probe

**Without disconnecting the first**, connect the second probe. Wait about two minutes.

**You should see:** **Sector 2 probe** starts showing readings too, and Sector 1 keeps working.

What happened: the board noticed a new probe using the factory address, and gave it the address
for sector 2 automatically.

## Step C3 — Add the third probe

Same again. Wait two minutes. **Sector 3 probe** should appear.

## Step C4 — Check they are the right way round

Hold **one** probe in your hand, or put it in a glass of water, and watch which sector's number
changes.

**Please record:** which physical probe corresponds to Sector 1, Sector 2 and Sector 3. Mark the
probes with tape so you do not lose track.

**If two probes ever show exactly the same number at exactly the same time,** they have ended up
sharing an address. Tell us — do not try to fix it yourself.

---

# Part D — The water tank sensor

Skip this part if no tank sensor is fitted.

The tank sensor is a float that moves up and down inside the tank. The board has to be told what
"empty" and "full" look like, because every tank is different.

## Step D1 — With the tank empty

1. Make sure the float is at the bottom (tank empty), or hold it at the bottom by hand.
2. On the board's page, find the **Water tank** section.
3. Press the button marked **Tare**. ("Tare" means "call this reading zero".)

**You should see:** the tank reading becomes 0%.

## Step D2 — With the tank full

1. Fill the tank, or hold the float at the top.
2. In the **Water tank** section, find the box next to **Calibrate**. Type `100` and send it.

**You should see:** the tank reading becomes 100%.

## Step D3 — Check it in between

Let the float sit at roughly half height.

**You should see:** somewhere near 50%. It does not need to be exact.

**Please record:** the readings at empty, half and full.

**If the reading goes DOWN as the tank fills up,** tell us — the sensor is wired the opposite way
to what we assumed, and it is a one-line change.

---

# Part E — The battery reading

The board measures the battery through two resistors. We need to know whether our arithmetic
matches your board.

**You cannot do this in one sitting** — you need the battery at different voltages, and the only
way to get that without special equipment is to wait. Three measurements over two days is enough.

## Step E1 — Measure and compare

Each time:

1. Measure the **actual** battery voltage with your multimeter, directly at the battery terminals.
2. Read the **Battery** value on the board's page. It is shown in millivolts, so 12.45 V appears
   as about `12450`.
3. Write both down, with the time.

**Please do this three times:**

| When | Meter reading (V) | Board reading (mV) |
|---|---|---|
| After dark, battery resting | | |
| Early morning, before the sun reaches the panel | | |
| Middle of a sunny day, while charging | | |

**What we are looking for:** whether the board's number is consistently a fixed percentage away
from the meter. If it is, that is one number for us to correct and it is easy. If the error
changes size at different voltages, that is more interesting and we need all three readings to
see it.

---

# Part F — A complete irrigation run

Now put it together. **Do this where spilled water does not matter**, or with the valves
connected to nothing.

## Step F1 — Set a start time two minutes from now

1. Look at the clock. Add two minutes. For example, if it is 14:37 now, your target is 14:39.
2. On the board's page, find the **Irrigation** section.
3. In **Start hour**, type the hour — `14` in this example. Send it.
4. In **Start minute**, type the minute — `39`. Send it.

## Step F2 — Set a short watering time

In the same section, find **Max minutes per sector** and set it to `1`. This is the longest any
one valve stays open. One minute keeps the test short.

## Step F3 — Make sure a sector actually wants water

A sector is only watered if its soil is drier than its target. Look at each sector's **Target**
and at the matching probe's moisture reading.

To force sector 1 to water: set its **Target** to a number **higher** than what the probe reads
now. If the probe reads 30, set the target to 90.

## Step F4 — Turn irrigation on

Find **Enabled** in the **Irrigation** section and switch it on.

## Step F5 — Watch

**You should see, at your target time:**

1. Valve 1 opens. **Active sector** shows `1`.
2. After at most one minute, valve 1 closes and valve 2 opens (or is skipped if sector 2 does not
   want water).
3. When all sectors are done, **Active sector** goes back to `0` and every valve is closed.

**Please record:** the time each valve opened and closed.

**If nothing happens at the target time:** check the clock again (step A3). This is the most
common cause by far.

## Step F6 — Check a sector with no probe is left alone

1. Disconnect the probe for sector 3.
2. Run the test again (steps F1 and F4 — you will need to set the time again).

**You should see:** sectors 1 and 2 behave as before, and valve 3 **never opens**. This is
deliberate: the board will not open a valve it has no measurement for.

---

# Part G — The charge controller's own measurements

The board can measure its solar panel and its own temperature. **None of this controls anything** —
the software only reads and reports. Controlling the charging comes later, and it will not be added
until these readings have been checked against your meter, because a charger working from a wrong
reading can damage a battery.

## Step G1 — The solar panel voltage

**Safety first.** A solar panel in daylight is live and cannot be switched off. Do not touch the
bare metal of the panel terminals. Measure at the board's terminals, with the panel connected.

1. Set your multimeter to **DC volts**.
2. Measure across the board's **solar panel** input terminals.
3. Read **Solar Panel** on the board's page. It is in millivolts, so 18.4 V appears as about
   `18400`.

Do this **three times on the same day**:

| When | Meter (V) | Board (mV) |
|---|---|---|
| Early morning, sun just reaching the panel | | |
| Middle of the day, full sun | | |
| Panel covered with a cloth or cardboard | | |

**What we are looking for:** whether the board's number tracks the meter, and whether the
difference stays the same size or grows as the voltage rises.

**If the board reads roughly zero all day** while your meter shows a real voltage, the panel is
probably connected to a different terminal than we assumed. Photograph the connections.

## Step G2 — Which temperature sensor is which

The board can have up to three temperature sensors on one shared pair of wires. They all look the
same to the software, so it has to be told which is which — **once**, and it remembers.

1. On the board's page you should see **Air Temperature**, **Battery Temperature** and
   **Board Temperature**. Some may show `--`, meaning nothing is assigned to them yet.
2. If more than one sensor is connected, each of those three has a **drop-down list** of the
   sensors found, showing long codes like `28a1b2c3d4e5f601`. That code is printed into the
   sensor at the factory and never changes.

### The easy way: connect them one at a time

If you can unplug the sensors, this is much easier than guessing, because at each step the code
that has just **appeared** is certainly the sensor you have just plugged in.

1. Disconnect all three sensors.
2. Connect **one**. Wait about a minute.
3. One code now appears in the drop-down lists. Choose it under the name that matches where that
   sensor is physically attached — for example, the one clipped to the battery goes under
   **Battery Temperature**. The choice is remembered, and survives switching the board off.
4. Connect the **second** sensor. Wait a minute. A second code appears. Assign it the same way.
5. Connect the **third**. You do not have to do anything: with only one name left unassigned and
   only one sensor unclaimed, the board matches them up by itself.

Write down each code and where that sensor is, so you have a record.

### The other way: if they are already all connected

If unplugging them is difficult, you can find each one by warming it:

1. Hold **one** sensor in your closed hand for a minute, or warm it gently. Do not use a flame.
2. Watch the three temperature readings. The one that rises is the sensor you are holding.
3. In the drop-down for the **correct name**, choose the code that just moved.
4. Repeat for each sensor.

**Please record:** each code and where that sensor is physically attached.

**If there is only one sensor connected in total,** it is assigned automatically and there is
nothing to do.

## Step G3 — Sanity-check the temperatures

With everything at room temperature and the board not working hard, all the sensors should read
within a degree or two of each other, and within a degree or two of the room.

**Please record:** the three readings, and the actual room temperature if you can measure it.

**If one reads about −127,** that sensor is not answering — check its wiring.

## Step G4 — The heatsink (only if question 4 applies)

If your board has the **pair of small diodes** near the heatsink rather than a temperature sensor
(see question 4 in [HARDWARE-QUESTIONS.md](HARDWARE-QUESTIONS.md)), tell us — we will send you a
build with that reading switched on. It is written but turned off by default, because we believe
most boards use the other method and having both would give two different answers to the same
question.

---

# Part H — Setting the charger by hand

**This is the most valuable measurement in this document.** It tells us how the number our
software sets relates to what the hardware actually does, which is the one thing we cannot work
out without your board.

The board controls charging by telling the solar charge circuit what voltage to hold the solar
panel at. Our software sets that as a number from **0 to 255**. We believe — but have not been
able to check — that:

- **0** asks for the lowest panel voltage, which draws the **most** charging current
- **255** asks for the highest panel voltage, which draws the **least**

So the number works backwards from what most people expect, and confirming that is part of the
point of this test.

## Before you start

**Conditions you need:**

- A **sunny day**, with the sun on the panel, and ideally not much cloud moving across.
- A battery that is **not already full** — early in the day is best. A full battery will not accept
  charge whatever we ask for, and the test will show nothing.
- About 30 minutes.

**Safety.** Do not disconnect the battery while the solar panel is connected. The battery is what
absorbs the panel's power; without it the charge circuit has nowhere to put it.

**This test cannot harm the battery.** Every setting asks for *less* charging than the panel could
give, or the same. Nothing here can overcharge anything. If you are worried at any point, set the
number back to **255**, which is the gentlest setting.

## Step H1 — Find the control

On the board's page, find the section called **Charge Control**. It has:

- **DAC step** — the box you type in, 0 to 255
- **Panel target** — what the software *predicts* the panel voltage will be. **This is a guess.**
  Checking it against your meter is exactly what this test does.
- **DAC volts** — an internal value; ignore it.

It starts at 255.

## Step H2 — Work through the settings

For each number in the table below:

1. Type it into **DAC step** and send it.
2. **Wait 30 seconds** for things to settle.
3. Measure the **solar panel** voltage with your meter, at the board's panel terminals.
4. Measure the **battery** voltage with your meter, at the battery terminals.
5. Write down both, and what the page shows under **Panel target**.

| DAC step | Panel target says (V) | Panel measured (V) | Battery measured (V) |
|---|---|---|---|
| 255 | | | |
| 230 | | | |
| 200 | | | |
| 170 | | | |
| 140 | | | |
| 110 | | | |
| 80 | | | |
| 50 | | | |
| 25 | | | |
| 0 | | | |

Please also note **roughly what the weather was doing** — full sun, thin cloud, and whether it
changed while you worked through the table.

## Step H3 — Put it back

When you have finished, set **DAC step** back to **255**.

## What we will learn

- Whether the panel voltage follows the step at all, and in which direction.
- Whether **Panel target** matches your measurements — if it is consistently out by the same
  proportion, our arithmetic has one wrong number in it, which is easy to correct.
- Where it stops responding. We expect the top of the range to be unreachable, and this shows
  whether that is so and by how much.
- Whether the battery voltage rises as you go towards 0, which is what "more charging current"
  should look like.

**If the panel voltage does not change at all** no matter what you type: tell us before doing
anything else. Either the connection to the charge circuit is not what we think it is, or that
part of the board works differently on your version.

---

# Part I — Letting it charge by itself

Only do this **after** Part H, and only if Part H's numbers looked sensible. Until you switch this
on, the board does not charge on its own at all.

## What it will do

Charging happens in two stages, like any proper charger.

**Stage 1, filling the battery.** Every five minutes it briefly stops charging, measures the solar
panel's voltage with nothing drawing from it, and then asks for about 80% of that — which for most
panels is close to the voltage that gives the most power. In between, it holds that setting.

**Stage 2, holding it full.** Once the battery has come up to the voltage it should be charged to,
the board stops chasing maximum power and instead makes small adjustments to *hold* the battery at
that voltage. If the battery later drops well below it — a pump switching on, or the sun going in
— it goes back to stage 1.

It also **lowers the voltage it charges to when things are warm**: a warm battery must be charged
to a slightly lower voltage than a cold one, and if the board's own heatsink gets hot it backs off
further. The **Target** line always shows the voltage actually being aimed at, so you can see this
happening.

It will stop, and stay stopped, if either the panel or the battery reading goes missing.

## Step I1 — Set the battery type

In the **Charge Control** section, set **Battery type** to match your battery:

| Type | Enter | Charge end | Lower by, per °C above 25 | If battery is over 42 °C |
|---|---|---|---|---|
| AGM | 0 | 14.10 V | 30 mV | 13.10 V |
| GEL | 1 | 14.10 V | 24 mV | 13.10 V |
| Flooded (wet, with caps you can open to add water) | 2 | 14.40 V | 30 mV | 13.30 V |
| LiFePO4 / Lithium | 3 | 14.20 V | none | 13.60 V |

Choosing a type fills in all three of those for you. You can then change any of them yourself if
you have been told different figures for your battery — your values will be kept.

**If you are not sure what battery you have, stop and ask.** Charging a battery to the wrong
voltage will shorten its life, and in the worst case can make a sealed battery vent gas.

## Step I1b — Make sure a temperature sensor is on the battery

The correction only happens if the board can measure the battery's temperature. In Part G you
assigned one of the temperature sensors to **Battery Temperature** — that sensor should be
physically attached to the battery, touching its case, not hanging in the air.

Check the **Charge Control** section shows a sensible **Battery temp**.

**If it shows `--`**, no correction is applied and **Target** will simply equal **Charge end**.
That is safe in cool weather but not in hot. If you cannot fit a sensor to the battery, set
**Charge end** about 0.3 V lower than the table says, and tell us the temperature the battery
reaches.

## Step I2 — Switch it on

Set **Automatic** to on.

## Step I3 — Watch what it says it is doing

The **State** line tells you what it is doing in one word:

| State | Meaning |
|---|---|
| `manual` | Automatic is off; it is using the number you typed |
| `sweeping` | Measuring the panel with nothing drawing from it — lasts a few seconds |
| `tracking` | Stage 1 — filling the battery as fast as the panel allows |
| `regulating` | Stage 2 — holding the battery at the target voltage |
| `too hot` | The board's heatsink is too hot, so it is deliberately charging less. See below |
| `overshoot` | The battery went well above the target, so charging was cut right back. Expect to
  see this briefly, if at all. If it stays there, tell us |
| `dark` | The panel has nothing useful to give |
| `no reading` | A sensor has stopped reporting. It has stopped charging on purpose |

**Please record, over one sunny day:**

| Time | State | Battery temp (°C) | Target (V) | Open circuit (V) | Panel measured (V) | Battery measured (V) |
|---|---|---|---|---|---|---|
| mid-morning | | | | | | |
| midday | | | | | | |
| mid-afternoon | | | | | | |
| after sunset | | | | | | |

**What we expect:** `tracking` in the morning, `regulating` once the battery fills, `dark` after
sunset, and the battery voltage close to **Target** while regulating.

**Worth checking while you are there:** if the battery warms up during the day, **Target** should
go *down* a little — about 30 mV for each degree. That is the temperature correction working.
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

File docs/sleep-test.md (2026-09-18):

# The sleep test — what the outputs do while the board is asleep

This one needs a **different build of the software**, and a multimeter. It is the last thing on
[Plan 3](plan-long-run.md), and it decides whether we can use a power-saving feature at all.

## Why

The board can be told to sleep when the battery is low, so that the solar panel gets a chance to
recharge it. But while an ESP32 sleeps, its output pins are normally *released* — they stop being
driven — and we do not know what this board does then.

The original software sets pin 14 with a "pull-up". If that still applies while the board is
asleep, it would switch the load **on** at exactly the moment we were trying to save power. And if
sleeping stops the charging, the battery cannot recover during the very sleep meant to let it.

Either way round, sleeping would make things worse rather than better, and we would leave the
feature switched off. It is off today for exactly this reason.

## The test build

There is a branch called `sleep-test`. It is the ordinary software with one thing changed: instead
of staying awake all the time, it **sleeps on a repeating cycle — 5 minutes awake, then 2 minutes
asleep, over and over**.

Nothing triggers it and nothing has to be timed. You wait for the next sleep, take your reading,
and if you miss it the window comes round again seven minutes later.

To build and flash it:

```bash
git checkout sleep-test
git pull
pio run --target upload --environment ff_openmppt
```

If you did not build the software yourself for
[Step A1](../TESTING.md#step-a1--put-the-software-on-the-board) but were sent a file to flash, you
will need a file for this too — ask, the same way.

### Knowing when it is asleep

- The board's page **stops responding**, and comes back about two minutes later.
- If the USB cable is plugged into a computer with a serial monitor open, this build prints
  `Sleeping` just before it goes.
- Waking is a full restart, so it reconnects to WiFi each time. Give it twenty seconds or so before
  expecting the page back.

That restart is also why irrigation goes back to idle after each sleep. That is normal and is not
what we are testing here.

## Which output to measure

**Pin 14**, which the board's page calls **Pump**. Use the same terminal you measured in
[Step B2](../TESTING.md#step-b2--switch-each-output-on-and-off), with the meter set up the same
way: black probe on the battery's negative terminal, red probe on the output.

The page calls it Pump because that is the role this software gives pin 14. The original OSPIT
software uses the same pin as its **load** switch — the one that would have the router on it — and
that is why this particular pin is the one worth measuring. It is the same pin and the same
circuit either way.

## The measurements

Six readings. Take them at the board's terminals with the meter, not from the page — the whole
question is what the hardware does when the software is not running.

**Pin 14 / Pump**

1. During an awake period, switch **Pump** on. Measure the voltage at its terminal. Write it down.
2. Wait for it to go to sleep. Measure the **same terminal again while it is asleep**. Does it stay
   on, or go off?
3. During the next awake period, switch **Pump** off. Measure the terminal.
4. Wait for the next sleep and measure again. Does it stay off, or come on?

Reading 4 is the one we are most worried about.

**The solar charging**

5. While it is awake and charging normally, note the **solar panel voltage** at the panel
   terminals.
6. Wait for it to sleep, and measure the panel voltage again while asleep. Does charging carry on,
   stop, or change?

Do 5 and 6 in reasonably steady sunshine if you can — a cloud crossing between the two readings
will change the voltage by itself and tell us nothing.

**While you are there**, if you have a spare moment during any sleep, put the probe on **Valve 1**
with the valve switched off and tell us what you see. A valve that comes on while the board is
asleep matters a good deal more than a router does, and it is the same measurement.

## Putting it back

```bash
git checkout main
pio run --target upload --environment ff_openmppt
```

The board then stays awake all the time again, as it does for every other test. Nothing you set on
the page is lost — settings live on the board and survive both the sleeping and the reflashing.

## What to send back

The six numbers, and for each of 2, 4 and 6, which of the outcomes it was. If the output behaved
differently on different sleeps, say so — an output that is inconsistent is a more interesting
answer than either of the tidy ones.

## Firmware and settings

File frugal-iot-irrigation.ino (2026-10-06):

/*
 *  Frugal IoT example - Irrigation controller
 *
 *  An irrigation controller, with optional MPPT power control. 
 *  
 *  Significant parts of this are inspired by 
 *  [OSPIT](https://www.apc.org/en/news/meet-ospit-sustainable-energy-and-irrigation-solution-community-networks)
 *  - the solar-powered irrigation controller built on the FF-ESP32-OpenMPPT board. 
 *  
 *  It currently waters a set of sectors one at a time, once a day, 
 *  each until its soil reaches a target moisture or a time limit runs out,
 *  with tank-level and battery interlocks that stop the whole run.
 * 
 *  That functionality is likely to change to meet varying needs of people using it, for example
 *  to allow multiple times a day, or per-sector variations. 
 * 
 *  Feedback on what functionality is needed is very welcome. 
 *
 *  To enable it to run on the OSPIT hardware, which is based on the Freifunk 
 *  [FF-ESP32-OpenMPPT](https://media.ccc.de/v/camp2023-57058-resilient_solar_energy_autonomous_infrastructure_with_freifunk_openmppt_controllers)
 *  board designed by Elektra Wagenrad, we've added MPPT. 
 *  In part based on some out of date code we found for it, but heavily modified. 
 * 
 *  What is here, and what is not:
 *    - irrigation, soil probes, tank gauge, valves, pump          YES
 *    - MPPT solar charge control                                  YES
 *
 *  Two boards are supported, see platformio.ini: `ff_openmppt` (the OSPIT version of the Freifunk board)
 *  and `s2_mini` (the same application on a plain dev board with no charge-controller hardware). 
 * 
 *  Adding other ESP32 boards should be as simple as copying their platformio.ini from one of the 
 *  examples in [frugal-iot](https;//github.com/mitra42/frugal-iot)
 *
 *  Ww anticipate the `s2_mini` will also evolve into a distributed version using sensors and valves
 *  connected by WiFi or LoRa.
 *
 *  ============================================================================================
 *  NOTE IRRIGATION IS OFF BY DEFAULT.
 *
 *  `irrigation/enabled` starts false - a device that opens water valves
 *  unattended should not begin doing so merely because it was flashed. 
 *  
 *  Turn it on once, from the captive portal or by publishing to `set/<device>/irrigation/enabled` = 1; 
 *
 *  Worth setting at the same time, all persisted the same way:
 *    irrigation/hour, irrigation/minute   when the daily run starts, local time (default 03:00)
 *    irrigation/maxminutes                longest any one valve may stay open (default 5)
 *    sectorN/target                       moisture % at which sector N is satisfied (default 80)
 * 
 *  All these settings are persisted in onboard LittleFS, and can also be flashed with platformio.ini 
 * 
 *  ============================================================================================
 */

#include "Frugal-IoT.h"
#include "control_irrigation.h"
#include "sensor_tank.h"
#include "control_oled_irrigation.h"
#include "sensor_heatsink.h"
#include "control_mppt.h"
#include "control_soc.h"
#include "control_health.h"
#include "language.h"

// Change the parameters here to match your ...
// organization, project, device name, description
System_Frugal frugal_iot(SYSTEM_FRUGAL_ORG, SYSTEM_FRUGAL_PROJECT, "irrigation", "Irrigation Controller");

void setup() {
  setupIrrigationLanguage();

  /* Battery sensor has to come before pre_setup, all others should come after.
   * The parameters are display parameters set in platformio.ini typically 10000..15000 mV for Lead Acid
   * For a single cell Lithium it would be 3000..5000 but this application is more likely to use multi-cell variants
   * The divider is set per board in platformio.ini - on the FF board it is OpenMPPT's own 1k/15k
   */
  #ifdef SENSOR_BATTERY_PIN
    frugal_iot.configure_battery(SENSOR_BATTERY_PIN, SENSOR_BATTERY_VOLTAGE_DIVIDER, SENSOR_BATTERY_MIN, SENSOR_BATTERY_MAX);
  #endif

  /* Awake all the time, on a 10 second cycle.
   *
   * Deliberately NOT a sleeping mode. Valve timing has the resolution of one wake cycle, and more
   * importantly a deep sleep in the middle of a run would abandon the run - Control_Irrigation
   * returns to idle in setup(). 
   * 
   * Control_Irrigation::okToSleep() is the hook used to stop a sleep, this is in progress in frugal-iot
   * and once hooked up we'll be able to use Power_Deep
   */
  frugal_iot.configure_power(Power_Loop, 10000, 10000);

  frugal_iot.pre_setup();
  syncIrrigationLanguage(frugal_iot.captive->language_code);

  // Override MQTT host, username and password if you have an "organization" other than "dev"
  frugal_iot.configure_mqtt("frugaliot.naturalinnovation.org", "dev", "public");

  // Add local wifis here, this is rarely used since a device without any wifi's can be setup 
  // via their captive portal, and will remember settings. Or have defaults flashed in /data
  //frugal_iot.wifi->addWiFi(F("mywifissid"),F("mywifipassword"));

  /* ---- Actuators: the valves, and optionally a pump and a load switch ------------------
   *
   * Two independent optional pins, so a board can have either, both, or neither:
   *   IRRIGATION_PUMP_PIN  driven by Control_Irrigation whenever irrigation is running
   *   IRRIGATION_LOAD_PIN  switched off by the battery interlock below
   * On the FF board both would be pin 14, so platformio.ini defines only one - see
   * OSPIT_COMPARISON.md for how OSPIT shares that pin.
   */
  frugal_iot.actuators->add(new Actuator_Digital("valve1", "Valve 1", IRRIGATION_VALVE1_PIN, DEFAULT_valve_on_color));
  frugal_iot.actuators->add(new Actuator_Digital("valve2", "Valve 2", IRRIGATION_VALVE2_PIN, DEFAULT_valve_on_color));
  frugal_iot.actuators->add(new Actuator_Digital("valve3", "Valve 3", IRRIGATION_VALVE3_PIN, DEFAULT_valve_on_color));
  #ifdef IRRIGATION_PUMP_PIN
    frugal_iot.actuators->add(new Actuator_Digital("pump", "Pump", IRRIGATION_PUMP_PIN, DEFAULT_pump_on_color));
  #endif
  #ifdef IRRIGATION_LOAD_PIN
    frugal_iot.actuators->add(new Actuator_Digital("load", "Load", IRRIGATION_LOAD_PIN, DEFAULT_load_on_color));
  #endif
  #ifdef IRRIGATION_USB_PIN
    // A second switched output, for a USB supply. On the FF board this is the SAME PIN as valve 3,
    // so define one or the other.
    frugal_iot.actuators->add(new Actuator_Digital("usb", "USB", IRRIGATION_USB_PIN, DEFAULT_usb_on_color));
  #endif

  // ---- Sensors -------------------------------------------------------------------------
  /* One RS485 bus, one probe per sector. A probe that does not answer publishes "nan", which is
   * what makes Control_Irrigation skip that sector 
   *
   * Slave ids start at 2, NOT 1. Address 1 is the factory default every probe ships with, and
   * SENSOR_SOILMODBUS_AUTOPROVISION needs it to keep meaning "not yet provisioned" - see
   * sensor/soilmodbus.h. With that flag set, commissioning is: plug in sector 2's probe, wait a
   * few cycles, plug in sector 3's, and so on IN ORDER.
   */
  System_RS485* rs485 = new System_RS485(&SYSTEM_RS485_UART);
  frugal_iot.sensors->add(new Sensor_SoilModbus("soil1", "Sector 1 probe", 2, rs485, true));
  frugal_iot.sensors->add(new Sensor_SoilModbus("soil2", "Sector 2 probe", 3, rs485, true));
  frugal_iot.sensors->add(new Sensor_SoilModbus("soil3", "Sector 3 probe", 4, rs485, true));

  // Resistive float sender in the tank. Publishes "nan" if no sender is fitted, which is NOT
  // treated as an empty tank - see sensor_tank.h.
  // TO-DO implement alternative ultrasonic sensor
  #ifdef SENSOR_TANK_PIN
    frugal_iot.sensors->add(new Sensor_Tank("tank", "Water tank", SENSOR_TANK_PIN, true));
  #endif

  /* ---- Charge controller instrumentation (P5.1) -------------------------------------------
   *
   * MEASUREMENT ONLY - the charge control below is what acts on these. 
   * So that each of these numbers can be checked against a multimeter before
   * any code acts on it, as a charge controller working from a wrong reading would damage a battery.
   *
   * Each is behind its own #define, so a board can be instrumented one piece at a time as the
   * questions in HARDWARE-QUESTIONS.md get answered.
   */
  #ifdef MPPT_PANEL_PIN
    /* Solar panel voltage.
     * The diode offset is in millivolts AT THE PIN, so the drop at the
     * panel is divided down: 300 mV through a 28:1 divider is about 11. Negative because the
     * panel is HIGHER than the pin suggests. 
     * On a FF board, set MPPT_PANEL_DIODE_MV to 0 if D6 has been replaced by a wire 
     * - see question 2 in HARDWARE-QUESTIONS.md.
     */
    frugal_iot.sensors->add(new Sensor_Voltage("panel", "Solar Panel", MPPT_PANEL_PIN,
      MPPT_PANEL_DIVIDER, DEFAULT_panel_panel_min, DEFAULT_panel_panel_max,
      -(MPPT_PANEL_DIODE_MV / MPPT_PANEL_DIVIDER), DEFAULT_panel_panel_color, true));
  #endif

  #ifdef SENSOR_HEATSINK_PIN
    // The diode-pair heatsink sensor. Most boards seem to use a DS18B20 for this instead, in which
    // case leave SENSOR_HEATSINK_PIN undefined and the class is not compiled at all.
    frugal_iot.sensors->add(new Sensor_Heatsink("heatsink", "Heatsink", SENSOR_HEATSINK_PIN, true));
  #endif

  #ifdef MPPT_ONEWIRE_PIN
    /* Up to three DS18B20 temperature probes on one shared wire.
     *
     * They are told apart by the unique id burned into each probe, not by position, so which is
     * which survives unplugging them - see "1-Wire" in the library's CLAUDE.md. With exactly one
     * probe on the bus it binds itself; with several, bind them from the captive portal, and the
     * choice is remembered.
     *
     * This is FF's owids.lua/owread.lua arrangement, which maps the same three ids to
     * airtemp, battery_temperature and heatsink_temperature.
     */
    frugal_iot.sensors->add(new Sensor_DS18B20("airtemp", "Air Temperature", MPPT_ONEWIRE_PIN, true));
    frugal_iot.sensors->add(new Sensor_DS18B20("batttemp", "Battery Temperature", MPPT_ONEWIRE_PIN, true));
    frugal_iot.sensors->add(new Sensor_DS18B20("pcbtemp", "Board Temperature", MPPT_ONEWIRE_PIN, true));
  #endif

  /* ---- Battery interlocks ----------------------------------------------------------------
   *
   * One Control_Hysteresis per thing that should give up when the battery gets low, each entirely
   * independent of the others and each behind its own #define. A board defines as many or as few
   * as it has pins for, and none of them knows about any other.
   *
   * The thresholds are what sets the ORDER things are shed in as the battery falls, and that is
   * the interesting decision:
   *
   *   USB supply      12.8 / 13.4   given up first - the least important consumer
   *   Irrigation      12.4 / 12.8   next: a pump is a big draw, and the watering can wait a day
   *   Load (router)   11.9 / 12.3   last, because losing communications means losing the ability
   *                                 to find out what went wrong
   *
   * Shedding the pump before the router is deliberate - it is the heaviest intermittent load. OSPIT
   * sheds both at once; see OSPIT_COMPARISON.md.
   *
   * Control_Hysteresis uses a limit with a dead-band so 12.1V +/- 0.2 is 11.9v off, 12.3v on
   */
  #ifdef IRRIGATION_LOAD_PIN
    Control_Hysteresis* chload = new Control_Hysteresis("controlhysteresis-load", "Load interlock",
      IRRIGATION_LVD_LOAD_MV, 0, 10000, 15000, IRRIGATION_LVD_LOAD_HYST_MV);
    frugal_iot.controls->add(chload);
    chload->inputs[0]->wireTo(frugal_iot.messages->path("battery/battery"));
    chload->outputs[0]->wireTo(frugal_iot.messages->setPath("load/on"));
  #endif

  #ifdef IRRIGATION_USB_PIN
    Control_Hysteresis* chusb = new Control_Hysteresis("controlhysteresis-usb", "USB interlock",
      IRRIGATION_LVD_USB_MV, 0, 10000, 15000, IRRIGATION_LVD_USB_HYST_MV);
    frugal_iot.controls->add(chusb);
    chusb->inputs[0]->wireTo(frugal_iot.messages->path("battery/battery"));
    chusb->outputs[0]->wireTo(frugal_iot.messages->setPath("usb/on"));
  #endif

  // Not conditional: irrigation is the point of this node, so it always has an interlock of its
  // own rather than borrowing the state of an output that may not exist.
  Control_Hysteresis* chirr = new Control_Hysteresis("controlhysteresis-irrig", "Irrigation interlock",
    IRRIGATION_LVD_IRRIGATION_MV, 0, 10000, 15000, IRRIGATION_LVD_IRRIGATION_HYST_MV);
  frugal_iot.controls->add(chirr);
  chirr->inputs[0]->wireTo(frugal_iot.messages->path("battery/battery"));


  // ---- Irrigation ------------------------------------------------------------------------
  Control_Irrigation* irr = new Control_Irrigation("irrigation", "Irrigation");
  frugal_iot.controls->add(irr);
  #ifdef SENSOR_TANK_PIN
    irr->tank->wireTo(frugal_iot.messages->path("tank/tank"));
  #endif
  #ifdef IRRIGATION_PUMP_PIN
    irr->pump->wireTo(frugal_iot.messages->setPath("pump/on"));
  #endif
  chirr->outputs[0]->wireTo(frugal_iot.messages->setPath("irrigation/power"));

  // Sectors run in the order they are added. addSector() registers each one as a control in its
  // own right, so each gets its own portal section, MQTT topics and discovery.
  Control_Sector* s1 = irr->addSector("sector1", "Sector 1");
  s1->moisture->wireTo(frugal_iot.messages->path("soil1/humidity"));
  s1->valve->wireTo(frugal_iot.messages->setPath("valve1/on"));

  Control_Sector* s2 = irr->addSector("sector2", "Sector 2");
  s2->moisture->wireTo(frugal_iot.messages->path("soil2/humidity"));
  s2->valve->wireTo(frugal_iot.messages->setPath("valve2/on"));

  Control_Sector* s3 = irr->addSector("sector3", "Sector 3");
  s3->moisture->wireTo(frugal_iot.messages->path("soil3/humidity"));
  s3->valve->wireTo(frugal_iot.messages->setPath("valve3/on"));

  #ifdef MPPT_DAC_PIN
    /* ---- Solar charge control ---------------------------------------------------------------
     *
     * The DAC tells the board's charge circuit what voltage to hold the solar panel at.
     * Control_MPPT finds the best voltage by briefly unloading the panel, measuring its
     * open-circuit voltage and then asking for about 80% of it - see control_mppt.h.
     *
     * AUTOMATIC IS OFF BY DEFAULT, so out of the box a person sets `mppt/step` by hand and watches
     * what happens - that is Part H of TESTING.md. Switch `mppt/automatic` on once the readings
     * have been checked against a meter. Either way it starts at the step that charges LEAST,
     * because the DAC is an inverse throttle and the safe fallback is the top of the range.
     */
    frugal_iot.actuators->add(new Actuator_Analog("analog", "Charge DAC", MPPT_DAC_PIN));
    Control_MPPT* mppt = new Control_MPPT("mppt", "Charge Control");
    frugal_iot.controls->add(mppt);
    mppt->dacvolts->wireTo(frugal_iot.messages->setPath("analog/volts"));
    #ifdef MPPT_PANEL_PIN
      mppt->panel->wireTo(frugal_iot.messages->path("panel/panel"));
    #endif
    mppt->battery->wireTo(frugal_iot.messages->path("battery/battery"));
    #ifdef MPPT_ONEWIRE_PIN
      mppt->batttemp->wireTo(frugal_iot.messages->path("batttemp/batttemp"));
      /* The heatsink reading comes from whichever sensor this board actually has: a DS18B20
       * on the 1-Wire bus, or the diode pair on an ADC pin. Both write the same meaning, and
       * only one is ever compiled - see question 4 in HARDWARE-QUESTIONS.md.
       */
      #ifndef SENSOR_HEATSINK_PIN
        mppt->heatsink->wireTo(frugal_iot.messages->path("pcbtemp/pcbtemp"));
      #endif
    #endif
    #ifdef SENSOR_HEATSINK_PIN
      mppt->heatsink->wireTo(frugal_iot.messages->path("heatsink/heatsink"));
    #endif
  #endif

  /* ---- Reporting: how full the battery is, and how well it is holding up -------------------
   *
   * Both are REPORTING ONLY. Nothing is controlled from either, and both publish read-only - a
   * voltage-derived estimate is fine to look at and useless to charge from, which is why
   * Control_MPPT does its own measuring rather than reading these.
   *
   * State of charge freezes while the panel is above the battery, because a battery on charge
   * reads high and tracking that would just report the charger. Battery health compares the
   * overnight fall in that estimate against the load you tell it about, and refuses to report at
   * all if irrigation ran during the window.
   */
  Control_SoC* soc = new Control_SoC("soc", "State of Charge");
  frugal_iot.controls->add(soc);
  soc->battery->wireTo(frugal_iot.messages->path("battery/battery"));
  #ifdef MPPT_PANEL_PIN
    soc->panel->wireTo(frugal_iot.messages->path("panel/panel"));
  #endif

  Control_Health* bh = new Control_Health("batteryhealth", "Battery Health");
  frugal_iot.controls->add(bh);
  bh->soc->wireTo(frugal_iot.messages->path("soc/soc"));
  bh->active->wireTo(frugal_iot.messages->path("irrigation/active"));

  /* ---- Display ---------------------------------------------------------------------------
   *
   * Three pages in a carousel, based on OSPIT's display.lua. It advances on its own; wire a
   * button to carousel/select/cycle, or publish to it, to step through by hand.
   */
  #ifdef ACTUATOR_OLED_WANT
    Control_Carousel* display = ospitDisplay();
    (void)display; // Nothing else to wire to it here - a button would go to carousel/select/cycle
    Control_Oled_IrrigationPower* powerPage = (Control_Oled_IrrigationPower*)display->controls[0];
    powerPage->battery->wireTo(frugal_iot.messages->path("battery/battery"));
    powerPage->soc->wireTo(frugal_iot.messages->path("soc/soc"));
    #ifdef MPPT_PANEL_PIN
      powerPage->panel->wireTo(frugal_iot.messages->path("panel/panel"));
    #endif
    #ifdef MPPT_DAC_PIN
      powerPage->mpptstate->wireTo(frugal_iot.messages->path("mppt/state"));
    #endif
    Control_Oled_IrrigationSoil* soilPage = (Control_Oled_IrrigationSoil*)display->controls[1];
    soilPage->moisture1->wireTo(frugal_iot.messages->path("soil1/humidity"));
    soilPage->moisture2->wireTo(frugal_iot.messages->path("soil2/humidity"));
    soilPage->moisture3->wireTo(frugal_iot.messages->path("soil3/humidity"));
    #ifdef SENSOR_TANK_PIN
      soilPage->tank->wireTo(frugal_iot.messages->path("tank/tank"));
    #endif
    soilPage->active->wireTo(frugal_iot.messages->path("irrigation/active"));
  #endif
  // Want NTP time (or set from browser)
  frugal_iot.system->add(frugal_iot.time = new System_Time());
  // Dont change below here - should be after setup the actuators, controls and sensors
  frugal_iot.setup(); // Has to be after setup sensors and actuators and controls and system
  Serial.println(F("FrugalIoT Starting Loop"));
}

void loop() {
  frugal_iot.loop(); // Should be running watchdog.loop which will call esp_task_wdt_reset()
  syncIrrigationLanguage(frugal_iot.captive->language_code);
}

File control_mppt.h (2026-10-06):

/* Control_MPPT - solar charge control for the FF-ESP32-OpenMPPT board.
 *
 * Finds the voltage at which the solar panel gives the most power, holds it there, and stops when
 * the battery is full. Ported from OSPIT's mp2.lua - the differences are in OSPIT_COMPARISON.md.
 *
 * ---------------------------------------------------------------------------------------------
 * What the DAC does, and which way round it is
 *
 * The board takes an analog voltage from the ESP32's DAC and uses it as the voltage the solar
 * panel should be held at. A panel produces most power at a particular voltage, below its
 * open-circuit voltage; holding it there is the whole job of an MPPT charger.
 *
 * The number is an INVERSE THROTTLE, which is easy to get backwards:
 *
 *     LOW  step -> low target voltage  -> the panel is pulled down hard -> MORE current
 *     HIGH step -> high target voltage -> the panel is left near open circuit -> LESS current
 *
 * So the SAFE value - the one that charges least, and the one to fall back on whenever a reading
 * is missing or a limit is reached - is the HIGHEST step, not zero.
 *
 * ---------------------------------------------------------------------------------------------
 * How a maximum power point is found: "fractional Voc"
 *
 * Measuring the true maximum power point needs a current sensor, which this board does not have.
 * The standard substitute exploits a property of silicon panels: the maximum-power voltage is a
 * fairly constant fraction of the open-circuit voltage, around 0.8, largely independent of how
 * bright it is. So:
 *
 *   1. Stop drawing current - write the highest step. The panel rises to its open circuit voltage.
 *   2. Wait for it to settle, then measure. That is Voc.
 *   3. Ask for Voc / CONTROL_MPPT_VOC_RATIO (1.24, i.e. 0.806 x Voc) and hold that until the next
 *      sweep.
 *
 * The cost is that charging stops during the sweep - here a whole wake cycle, because the panel
 * voltage arrives through the normal sensor path. So CONTROL_MPPT_SWEEP_S (default 300) sweeps far
 * less often than OSPIT does; Voc moves over tens of minutes, so little tracking accuracy is lost.
 *
 * ---------------------------------------------------------------------------------------------
 * The sweep is spread across two wake cycles, not blocking
 *
 * Cycle N     : write the highest step, note the time, enter SWEEPING.
 * Cycle N+1   : the sensors have since read the panel with no load on it, so `panel` now holds
 *               Voc. Compute the setpoint, write it, go back to TRACKING.
 *
 * This works because System_Frugal runs the sensors group before the controls group, so by the
 * time this control's periodically() runs, the panel reading is from this cycle. It is also why
 * the control reads the panel through a wired IN rather than reaching into the sensor: nothing
 * has to block, and nothing has to know which pin the panel is on.
 *
 * ---------------------------------------------------------------------------------------------
 * Safety - what this will and will not do
 *
 * Every path that is not a deliberate decision to charge ends at the safe step:
 *
 *   no reading from the panel or the battery   -> safe. A charger acting on a missing reading is
 *                                                 the failure that damages batteries.
 *   battery at or above the charge-end voltage -> safe, until it falls CONTROL_MPPT_RESUME_MV
 *                                                 below it again. This is the charge limit.
 *   panel below the battery, or Voc barely above it -> dark. See CONTROL_MPPT_IDLE_STEP.
 *   automatic switched off                     -> whatever step a person last asked for.
 *
 * ---------------------------------------------------------------------------------------------
 * Two stages: bulk, then absorption
 *
 * TRACKING is the bulk stage - take whatever the panel will give, at the maximum power point.
 * That is right until the battery approaches the voltage it should be charged to; past that,
 * pushing more current in overcharges it. So once the battery rises CONTROL_MPPT_ENTER_MV above
 * the target the controller switches to REGULATING, where it stops chasing maximum power and
 * instead nudges the step up or down to HOLD the battery at the target. It returns to bulk when
 * the battery has fallen CONTROL_MPPT_EXIT_MV below the target - a wide gap, because a load
 * switching on should not be mistaken for the battery discharging.
 *
 * The regulator is proportional and slew-limited, because it runs only once a wake cycle:
 *
 *     delta = error / CONTROL_MPPT_REGULATE_MV_PER_STEP, clamped to CONTROL_MPPT_MAX_SLEW
 *
 * If field testing shows it oscillating, lower the gain or the slew; if it is sluggish, raise
 * them. Both are build flags.
 *
 * CONTROL_MPPT_OVERSHOOT_MV is the backstop that makes the slow loop safe: past that much above
 * the target the controller stops arguing and goes straight to the safe step. Whatever the gain
 * is doing, the battery cannot be held far above its charge voltage.
 *
 * ---------------------------------------------------------------------------------------------
 * Temperature
 *
 * Two corrections, both of which LOWER the voltage the battery is charged to:
 *
 *   Battery temperature. Lead-acid wants about -30 mV per degree above 25 C (per cell-string; the
 *   figure is per profile). A hot battery charged to a cold battery's voltage gases and loses
 *   water. Above CONTROL_MPPT's hot limit the target is clamped to the profile's hot-battery
 *   voltage outright rather than extrapolating.
 *
 *   Heatsink temperature. TWO mechanisms, and the distinction matters:
 *
 *   A HARD CUT at CONTROL_MPPT_MAX_C. At or above it, charging stops at once - one cycle, whatever
 *   the battery is doing - and stays stopped until the board has cooled to
 *   CONTROL_MPPT_DERATE_RESTORE_C. This is what actually guarantees the temperature stays under
 *   the limit, and it is the only thing that can: any gradual scheme keeps charging while it works,
 *   and a board that is still charging is still heating.
 *
 *   A PROGRESSIVE BACKOFF from the lower CONTROL_MPPT_DERATE_START_C, which subtracts
 *   CONTROL_MPPT_DERATE_STEP_MV from the target on each cycle still above it. This is OSPIT's only
 *   mechanism. It is kept because near the end of charge it settles the board gently, but it cannot
 *   be the only one: lowering the target does nothing while the battery is below it, so with a
 *   discharged battery - the one making the most heat - it is slowest to act. Do NOT cap the total
 *   backoff; that stops it ever engaging. Measurements in OSPIT_COMPARISON.md.
 *
 *   CONTROL_MPPT_TARGET_MIN_MV exists only to stop the arithmetic reaching values that mean
 *   nothing; it sits below any usable battery, so it never limits anything.
 *
 * With no battery temperature sensor wired, no compensation is applied and `target` simply equals
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

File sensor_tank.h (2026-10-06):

/* Sensor_Tank - water tank level, in percent, from a resistive float sender.
 *
 * ---------------------------------------------------------------------------------------------
 * The circuit
 *
 * A float sender is a variable resistor whose resistance follows the float. Wire it as the lower
 * half of a voltage divider, with a fixed resistor from 3v3 to the ADC pin and the sender from the
 * pin to ground:
 *
 *     3v3 ---[ R fixed ]---+--- ADC pin
 *                          |
 *                     [ R sender ]
 *                          |
 *                         GND
 *
 * The pin then sits at 3.3 x Rsender / (Rsender + Rfixed), so the raw ADC reading rises and falls
 * with the level. Senders come in both directions (low resistance at empty or at full), and either
 * works: calibration just maps whatever the two ends read onto 0% and 100%.
 *
 * Choose Rfixed so that "full" reads well below the top of the ADC range. That leaves a gap at the
 * top for the next case.
 *
 * ---------------------------------------------------------------------------------------------
 * "No sender" is not "empty tank"
 *
 * With the sender unplugged or its cable broken, nothing pulls the pin down, so the fixed resistor
 * pulls it up to 3v3, near the top of the range. No connected sender can read that high. So:
 *
 *   raw >= SENSOR_TANK_RAW_DISCONNECTED -> validate() fails -> publishes "nan"
 *   otherwise                           -> a level, 0..100 %
 *
 * Control_Irrigation relies on the difference: "nan" means there is no tank sensor, which must not
 * block irrigation, while a genuine low level must stop it. Anything using this sensor should make
 * the same distinction.
 *
 * ---------------------------------------------------------------------------------------------
 * Converting to percent
 *
 * Sensor_Analog computes (raw - offset) x scale. Here offset is the empty reading and scale is
 * 100 / (full - empty), so the empty reading becomes 0% and the full one 100%. The result is
 * clamped to 0..100, so a sender slightly out of calibration reads 100% rather than 103%.
 *
 * ---------------------------------------------------------------------------------------------
 * Calibrating it
 *
 * From the captive portal, which is easiest and is persisted: with the tank empty press Tare, then
 * with it full enter 100. See captiveLines() below.
 *
 * Or at build time, with the raw counts measured at both ends:
 *   SENSOR_TANK_RAW_EMPTY         (0)     counts with the tank empty
 *   SENSOR_TANK_RAW_FULL          (703)   counts with the tank full
 *   SENSOR_TANK_RAW_DISCONNECTED  (3000)  at or above this, the sender is assumed missing
 *
 * The defaults are calculated, not measured, for a 0 ohm (empty) to 170 ohm (full) sender with an
 * 820 ohm fixed resistor: full is 0.567 V, about 703 counts of a 12-bit ADC at 11 dB attenuation.
 * That is the sender OSPIT uses; its own code only detects whether the sender is present, not the
 * level - see OSPIT_COMPARISON.md.
 *
 * Published as <id>/<id>, e.g. "tank/tank", per Sensor_Float's one-output convention.
 */

#ifndef SENSOR_TANK_H
#define SENSOR_TANK_H

#include "sensor/analog.h"

#ifndef SENSOR_TANK_RAW_EMPTY
  #define SENSOR_TANK_RAW_EMPTY 0
#endif
#ifndef SENSOR_TANK_RAW_FULL
  #define SENSOR_TANK_RAW_FULL 703
#endif
#ifndef SENSOR_TANK_RAW_DISCONNECTED
  #define SENSOR_TANK_RAW_DISCONNECTED 3000
#endif

class Sensor_Tank : public Sensor_Analog {
  public:
    Sensor_Tank(const char* const id, const char* const name, uint8_t pin, bool retain,
                int raw_empty = SENSOR_TANK_RAW_EMPTY,
                int raw_full = SENSOR_TANK_RAW_FULL,
                int raw_disconnected = SENSOR_TANK_RAW_DISCONNECTED);
  protected:
    int raw_disconnected;
    bool validate(int v) override;
    float convert(int v) override;
    /* Two-point calibration from the portal, the same mechanism Sensor_Soil offers.
     *
     * Sensor_Analog already has it all: writing 0 to <id>/output tares (the current raw reading
     * becomes 0%), writing any other number calibrates (scale is set so the current reading means
     * that number), and both offset and scale are persisted. The constructor's raw_empty/raw_full
     * are only the starting point.
     */
    void captiveLines(AsyncResponseStream* response) override;
};

#endif // SENSOR_TANK_H

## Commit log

2026-09-13 examples/ospit - sequenced soil-moisture irrigation, a port of OSPIT's irrigation.lua
    P2: everything OSPIT's irrigation does except MPPT. Waters a list of sectors one at a time, once
    a day at a configured local time, each until its soil reaches a target or a time limit expires,
    with tank-level and battery interlocks that stop the whole run.
    Three new classes, deliberately in the example rather than in src/. The control options are
    expected to be wrong for the next application that needs them, so they are somewhere a person can
    copy and edit rather than somewhere a person has to extend.
    Control_Irrigation the sequencer - clock, interlocks, pump, ordered list of sectors
    Control_Sector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
    [min_spiffs.csv]
2026-09-13 examples/ospit: use the new setters, and one schema entry per module rather than per instance
    - Control_Sector::setEnable is gone; enable->set() does the same job now that INbool has one.
    - The battery interlock gets its 200mV dead band from the constructor, so the "set it from the
    portal by hand" TODO in ospit.ino goes away.
    - The valves take DEFAULT_valve_on_color rather than DEFAULT_valve1/2/3_on_color: with
    frugal-iot-client resolving soil1 -> soil and valve2 -> valve, the schema needs only one entry
    per module however many instances a node has, and the numbered entries have been dropped from
    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
2026-09-13 Close every valve at the end of a run, and let the tank and battery be calibrated
    Three fixes found by extending the host harness to model the relay separately from the control's
    OUT value - which is the distinction that mattered, because OUTbool::set() only sends on a change.
    1. A valve opened by hand from the portal was never closed by the sequencer.
    The manual toggle goes to the Actuator_Digital, so Control_Sector's own OUT still reads false;
    stop()'s set(false) therefore had nothing to send and the relay stayed open. Worse, stop() is
    only reached for the sector that actually ran, so a manually opened valve on a skipped or
    already-wet sector was never even considered.
    cl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
    [sensor_tank.h]
2026-09-13 examples/ospit: separate pump and load pins, Modbus auto-provisioning, and the OLED pages
    Pump and load are now two independent optional pins (#3)
    OSPIT has ONE output, pin 14, with two possible roles chosen by pump_is_load: a pump the
    irrigation sequence drives with each valve (false), or a load output the low-voltage disconnect
    opens (true). Splitting them into OSPIT_PUMP_PIN and OSPIT_LOAD_PIN lets a board have either,
    both, or neither. The FF env defines the pump and carries the load line commented out, because
    on that board they would be the same pin; the S2 has pins to spare and defines both, which also
    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
2026-09-14 Make this a standalone project: builds in PlatformIO and in the Arduino IDE
    Split out of frugal-iot's examples/ospit with `git subtree split`, so the four commits above are
    the real history of these files rather than a fresh import.
    Layout is deliberately FLAT - the sketch and its .cpp/.h at the top of the repo - because that is
    the only shape that builds in both toolchains. The Arduino IDE needs a .ino whose name matches the
    folder (hence frugal-iot-irrigation.ino) and compiles the files beside it, ignoring every
    subdirectory except src/; PlatformIO is told src_dir = . and compiles the same set.
    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
2026-09-14 TESTING.md and HARDWARE-QUESTIONS.md, for someone who has the board and we do not
    Written for a reader who is competent with a multimeter but is not a developer, does not know this
    code, and does not have English as a first language. So: no jargon without a definition ("Tare"
    means "call this reading zero"), exact click paths rather than "set the start time", and every
    step says what you should see AND what it means if you see something else.
    No bench supply is assumed anywhere. That mainly changes the battery check, which becomes three
    readings taken over two days at naturally different states of charge rather than a sweep - slower,
    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
2026-09-14 P5.1: instrument the charge controller board, without controlling anything
    Measurement only. Nothing here drives the charger - that is P5.2 onwards. Doing it separately is
    the point: every one of these numbers can be checked against a multimeter before any code acts on
    it, and a charge controller working from a wrong reading damages a battery.
    Solar panel voltage Sensor_Voltage from the library, not a class of its own - it is the same
    job as the battery reading with a different divider (1k/27k = 28, the
    0.035714 in mp2.lua's Vinmeasure). The D6 Schottky drop is expressed as
    an OFFSET in millivolts AT THE PIN, so 300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
    [frugal-iot-irrigation.ino]
2026-09-14 P5.2: drive the solar charge controller by hand, and settle the board-revision question
    Control_MPPT, which at this stage tracks nothing. A person sets a DAC step and watches what the
    panel and the battery do; the sweep and the regulation loop are P5.3 and P5.4, deliberately not
    written until the manual version has been driven on real hardware.
    The setpoint is exposed as a RAW STEP (0-255), not as a panel voltage, and that is the important
    design decision here. The mapping from step to panel voltage is precisely what the field test is
    meant to measure - so if we asked the tester to set a voltage, a wrong mapping would quietly
    corrupt the table meant to reveal it. Instead `step` is an input,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
    [control_mppt.h, frugal-iot-irrigation.ino]
2026-09-14 P5.3: fractional-Voc tracking - the charge controller can now run on its own
    Control_MPPT finds the voltage at which the panel gives most power, holds it there, and stops when
    the battery is full. Ported from OSPIT's mp2.lua.
    How it finds the point: this board has no current sensor, so the true maximum cannot be measured.
    The standard substitute is that a silicon panel's maximum-power voltage is a fairly constant
    fraction of its open-circuit voltage - about 0.8, largely independent of brightness. So: stop
    drawing current, let the panel rise to open circuit, measure, then ask for Voc/1.24.
    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
2026-09-14 P5.4: two-stage charging, temperature compensation and heatsink derating
    The charge controller is now complete as a controller. What is left from OSPIT's mp2.lua is
    reporting - state of charge and battery health - not control.
    TWO STAGES. Tracking the maximum power point is right until the battery approaches the voltage it
    should be charged to; past that, more current overcharges it. So once the battery rises
    CONTROL_MPPT_ENTER_MV above the target the controller stops chasing power and instead nudges the
    step to HOLD the battery there, returning to bulk when it falls CONTROL_MPPT_EXIT_MV below. The
    exit gap is deliberately wide so a pump switching on is not mistaken for the battery needing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
    [control_mppt.h, frugal-iot-irrigation.ino]
2026-09-14 Heatsink derating: remove the cap I added - it prevented the protection from working
    Mitra asked whether a board that stays hot should not walk its charge voltage down until charging
    stops. It should, and the cap I put on the derating in P5.4 was wrong.
    Lowering the target does NOTHING while the battery is below it: in the bulk stage the target is
    not used for current control at all, only to decide when to start regulating. The derate begins
    to bite only once the target has fallen BELOW the battery's actual voltage.
    So with AGM's 14.1V and my 1000mV cap, the target stopped at 13.1V. A discharged battery under
    charge sits around 13.0V - still below that - so the board stayed in bulk at full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
    [control_mppt.h]
2026-09-14 Heatsink: cut charging hard at the temperature limit, not gradually
    Mitra: "if we hit a maximum temperature we should cut, we want the temperature always below
    maximum, and worse if we are still charging the temperature could still be rising."
    Right, and it is the argument against every gradual scheme: a ramp cannot bound a temperature,
    because the board goes on heating for as long as it goes on charging. Measured, the ramp took
    between 30s and 180s to stop charging depending on the battery's voltage - and the slow end was the
    discharged battery, which is the one drawing the most current and making the most heat. Response
    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
2026-09-15 P5.5: USB supply interlock, and the low-voltage sleep left switched off on purpose
    The rest of P5.5 turned out to be already done - heatsink derating landed in P5.4, and the
    low-voltage load disconnect has been there since P2 as a Control_Hysteresis on the battery. What
    was left is the USB output and the low-voltage deep sleep.
    USB SUPPLY. A second switched output with its own interlock, at a HIGHER threshold than the load:
    off below 12.8V, on above 13.4V, which is a limit of 13.1 with a 300mV dead band. Higher on
    purpose - as the battery falls it sheds the less important consumer first, and only takes the
    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
2026-09-18 platform.h was stale: seven defines the Arduino IDE was not getting
    Regenerating it after an unrelated change to platformio.ini turned up 41 lines that should have
    been there already. Two commits forgot to run scripts/generate_platform_h.bash:
    0d13975 (P5.5) SYSTEM_POWER_BAD_READING_MV
    cd665a1 the whole build_flags_lvd section - all six OSPIT_LVD_* thresholds
    PlatformIO never noticed, because PlatformIO does not read platform.h; it reads platformio.ini.
    Only the Arduino IDE path was affected, and there it would not have been subtle - the .ino names
    OSPIT_LVD_LOAD_MV directly, so an Arduino build of a board with OSPIT_LOAD_PIN set would simply
    have failed to compile. A board wi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
2026-09-22 S2 mini wiring diagram and schematic
    [bom.csv, driver_switch.kicad_sch, driver_valve.kicad_sch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]
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2026-10-28 2.0.7 support frugaliot-irrigation-v0.1; Rework classes and timer so can easier subclass for different sector needs etc
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
